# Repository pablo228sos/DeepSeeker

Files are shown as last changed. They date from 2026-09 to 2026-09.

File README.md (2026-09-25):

# DeepSeeker

[English](README.md) | [Русский](README.ru.md)







**A field-evaluated autonomous catamaran for synchronized shallow-water imaging and coverage guidance at Lake Issyk-Kul.**

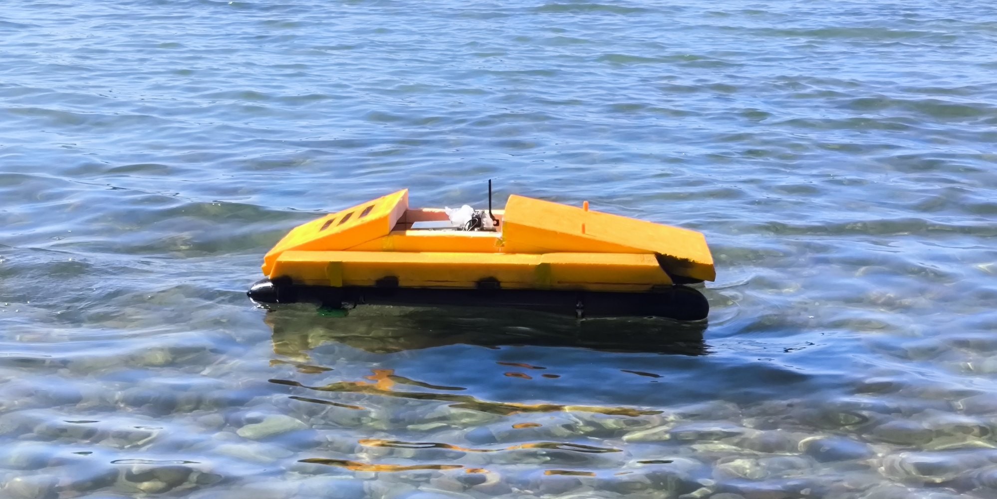
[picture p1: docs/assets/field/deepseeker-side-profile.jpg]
DeepSeeker operating in shallow water at Lake Issyk-Kul


DeepSeeker is a low-cost robotic catamaran built to survey shallow water, capture geotagged underwater imagery, and turn a planned coverage route into a dataset that can be inspected and reconstructed later. The system was designed, assembled, programmed, and tested during the Young Scientists Camp 2026 at Lake Issyk-Kul, Kyrgyzstan.

This repository preserves the recovered engineering record: field firmware, camera firmware, mission-planning tools, raw mission archives, telemetry, reconstruction attempts, successful results, hardware models, and the final research paper. Failed trials are kept beside the successful run because they explain which changes mattered.

<p align="center">
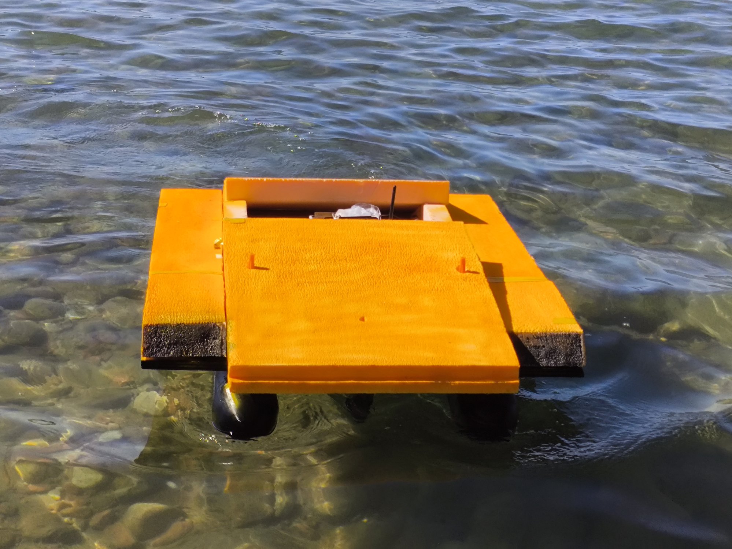
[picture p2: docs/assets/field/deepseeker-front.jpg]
Front view of DeepSeeker in shallow water
  
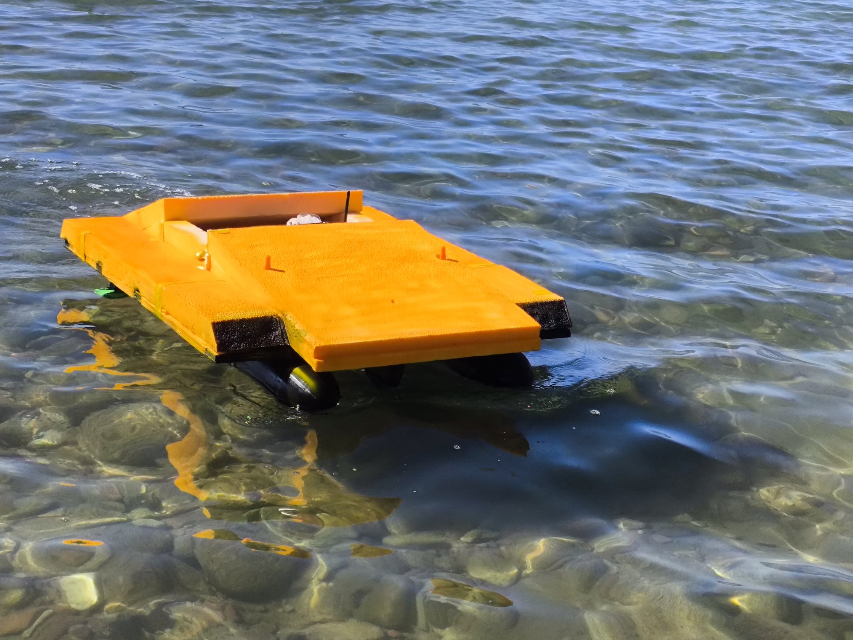
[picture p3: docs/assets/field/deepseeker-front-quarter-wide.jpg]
Front-quarter field view of DeepSeeker
  
</p>

## Mission

We set out to build a small surface vehicle that could define a survey area, follow a coverage pattern, photograph the bottom, and leave behind enough synchronized evidence to reconstruct and audit the mission later. The harder goal was not merely making the boat move. It was connecting navigation, imaging, storage, and honest validation into one field system.

## Field result at a glance

| M0016 measure | Result |
| --- | ---: |
| Images saved | 208 / 208 |
| Mission duration | 279 s |
| Median speed | 0.262 m/s |
| Median capture time | 445.5 ms |
| Median satellites | 6 |
| Median HDOP | 1.56 |
| Connected reconstruction | One outbound-and-return bottom transect |

## System

- A twin-thruster surface catamaran controlled by an ESP32.
- An ESP32-S3 camera node with microSD storage and a downward-looking OV3660 camera.
- GPS, MPU-6050 inertial sensing, differential thrust, manual Wi-Fi control, and autonomous coverage logic.
- Synchronized JPEG, GNSS, IMU, stability, and capture-time logging.
- Four-corner survey definition and lawnmower-style coverage experiments.
- An OpenDroneMap-compatible `geo.txt` export for georeferenced processing.
- A custom feature-aligned corridor reconstruction for the strongest field mission.

## Strongest field result

Mission **M0016** recorded 208 geotagged underwater images during a manually controlled outbound-and-return transect. Every expected frame was saved. The mission lasted 279 seconds, with a median speed of 0.262 m/s and a median image capture time of 446 ms. The GPS solution usually used 5-6 satellites; median HDOP was 1.56.

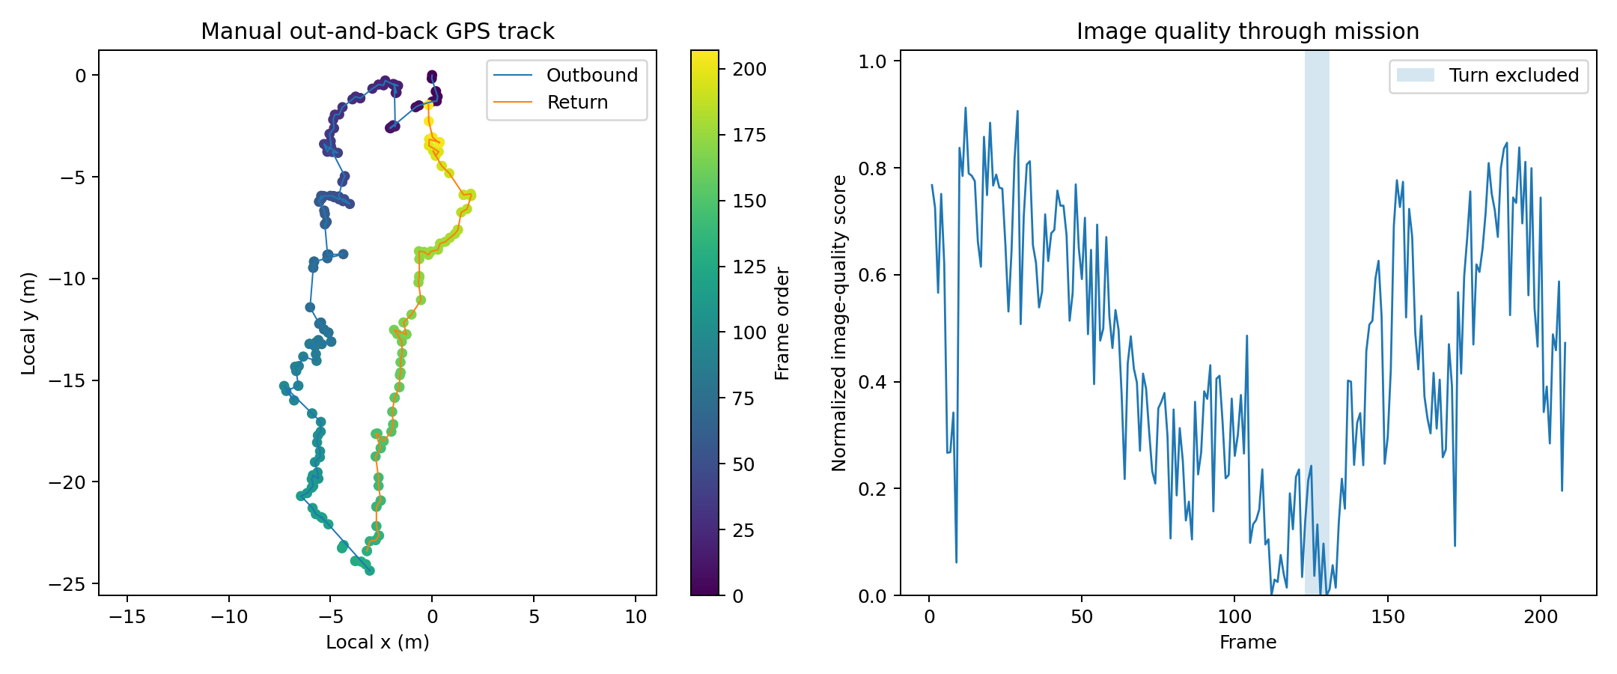
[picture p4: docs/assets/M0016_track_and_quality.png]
M0016 route and image quality


The final processing produced a connected view of the surveyed bottom corridor. It is useful as a visual transect and demonstrates that low-cost synchronized imaging can preserve interpretable bottom texture under field conditions.

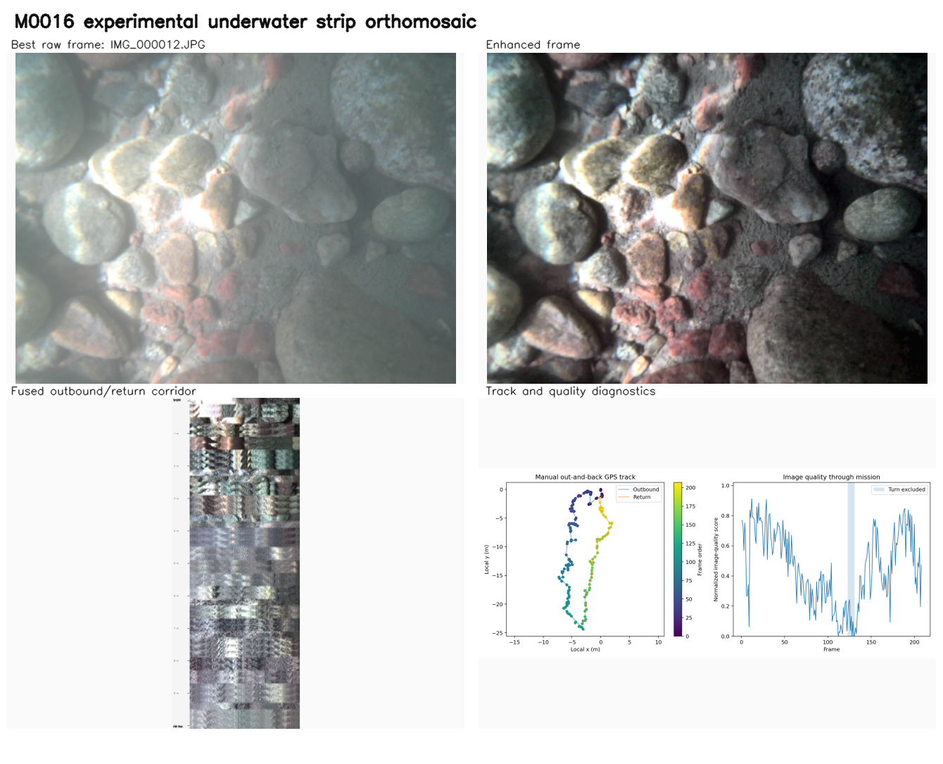
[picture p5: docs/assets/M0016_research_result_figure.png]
M0016 experimental strip mosaic


We deliberately call this an **experimental strip mosaic**, not a survey-grade orthophoto. The run covered one out-and-back corridor rather than a complete grid, the underwater camera was not metrically calibrated, camera height was not measured, and consumer GNSS does not provide survey-grade placement.

## Repository map

| Path | Contents |
| --- | --- |
| [`firmware/`](firmware/) | Main ESP32 controller, ESP32-S3 camera node, field mode, and version history |
| [`data/`](data/) | Raw M0014 and M0016 archives, telemetry, `geo.txt`, metrics, and derived results |
| [`analysis/`](analysis/) | Reproducible mission summaries and diagnostic plots |
| [`docs/`](docs/) | Architecture, hardware, field procedure, navigation, imaging, results, and limitations |
| [`hardware/`](hardware/) | Sonar-mount CAD files and hardware notes |
| [`tools/`](tools/) | AquaRoute mission planner and DRSKHUB ground-station prototype |
| [`research/`](research/) | Final 21-page project paper |

## Archive completeness

| Artifact | Status |
| --- | --- |
| Final main-controller firmware | Recovered, checksummed, and compiled |
| Final ESP32-S3 camera firmware | Recovered, checksummed, and compiled |
| M0014 raw mission | Recovered: 362 JPEG images, telemetry, and `geo.txt` |
| M0016 raw mission | Recovered: 208 JPEG images, telemetry, and `geo.txt` |
| Derived diagnostics and mosaics | Recovered and preserved with method notes |
| Original physical microSD card | Lost after the camp |
| Original one-off feature-alignment script | Not recovered; outputs and telemetry-level reproduction are preserved |

The distinction matters: this repository contains every recovered primary artifact, but it does not pretend that missing source material was recovered. See [`docs/reproducibility.md`](docs/reproducibility.md).

## Quick start

Git LFS is required for the two raw mission archives. Python 3.10 or newer is sufficient for the numerical summary.

```bash
git lfs install
git clone https://github.com/pablo228sos/DeepSeeker.git
cd DeepSeeker
python -m pip install -r analysis/requirements.txt

python analysis/deepseeker_analysis.py summarize data/M0016/source/telemetry.csv
python analysis/deepseeker_analysis.py plot \
  data/M0016/source/telemetry.csv \
  --quality-csv data/M0016/derived/M0016_quality_metrics.csv \
  --turn-start 123 \
  --turn-end 131 \
  --output M0016_reproduced.png
```

The raw images are preserved in `data/M0014/raw/M0014.rar` and `data/M0016/raw/M0016.rar`. Their SHA-256 checksums are recorded in [`data/manifest.csv`](data/manifest.csv).

## Imaging workflow

The camera firmware writes each image and its synchronized metadata to microSD. `geo.txt` follows the OpenDroneMap geolocation-file format with `EPSG:4326`, image name, longitude, latitude, and altitude. It can be placed in the image project root for ODM or WebODM processing.

[OpenDroneMap](https://github.com/OpenDroneMap/ODM) was the intended general photogrammetry pipeline. The successful M0016 figure in this repository was produced with a separate feature-aligned corridor workflow because the mission was a single transect and underwater imagery violated several assumptions of ordinary aerial orthophoto reconstruction. See [`docs/imaging-and-mosaics.md`](docs/imaging-and-mosaics.md).

## Read this before reusing the results

DeepSeeker was tested in a real lake with waves, turbidity, moving sunlight, GNSS drift, optical-window effects, and limited field time. These are research data, not certified hydrographic measurements. The project demonstrates a working embedded acquisition platform and a useful visual reconstruction, while documenting the limits that still prevent metric underwater mapping.

Start with:

- [`docs/results.md`](docs/results.md) for the measured outcomes.
- [`docs/limitations.md`](docs/limitations.md) for what the data cannot prove.
- [`docs/field-operations.md`](docs/field-operations.md) before running the vehicle.
- [`docs/bill-of-materials.md`](docs/bill-of-materials.md) for the recovered hardware configuration.
- [`docs/gallery.md`](docs/gallery.md) for field photographs.
- [`docs/roadmap.md`](docs/roadmap.md) for the next validation steps.
- [`research/DeepSeeker_Final_Submission_Mobile_Safe.pdf`](research/DeepSeeker_Final_Submission_Mobile_Safe.pdf) for the complete paper.

## Team

DeepSeeker was developed by **Abai Bakasov, Aikanysh Muratbekova, Najmidin Takhirov, Sharifjon Farmonov, Dinislam Muratov, and Zhuoyin Li** during the Young Scientists Camp 2026.

## License and citation

Source code is released under Apache-2.0. Original documentation, figures, media, and datasets are released under CC BY 4.0 unless a file states otherwise. See [`LICENSE`](LICENSE), [`LICENSE.md`](LICENSE.md), and [`CITATION.cff`](CITATION.cff).

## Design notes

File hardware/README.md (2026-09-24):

# Hardware artifacts

`cad/sonar_mount_v1.stl` and `cad/sonar_mount_v2.stl` preserve two mechanical iterations for the experimental sonar assembly.

The final research claim is based on synchronized camera, GNSS, and IMU acquisition. Sonar depth and material-classification experiments were inconclusive and are documented as development history rather than validated sensing results.

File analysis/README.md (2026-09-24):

# Analysis

`deepseeker_analysis.py` recalculates mission-level metrics directly from camera telemetry and creates a route and quality diagnostic.

## Setup

```bash
python -m pip install -r analysis/requirements.txt
```

The `summarize` command uses only the Python standard library. Matplotlib is required only by `plot`.

## M0016

```bash
python analysis/deepseeker_analysis.py summarize \
  data/M0016/source/telemetry.csv \
  --output analysis/output/M0016_summary.json

python analysis/deepseeker_analysis.py plot \
  data/M0016/source/telemetry.csv \
  --quality-csv data/M0016/derived/M0016_quality_metrics.csv \
  --turn-start 123 \
  --turn-end 131 \
  --output analysis/output/M0016_track_and_quality.png
```

`raw_gps_polyline_m` is the sum of distances between consecutive raw GNSS fixes. It includes GNSS jitter and must not be presented as a calibrated traveled distance.

## Tests

```bash
python -m unittest discover -s analysis/tests -v
```

The historical M0014 and M0016 derived packages are preserved exactly as recovered. The script here provides a clean, reviewable baseline for repeating their telemetry-level analysis.

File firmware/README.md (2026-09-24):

# Firmware

## Final field snapshots

### Main controller

`main-controller/main_esp32_autonomy_v6_0_interlaced_teardrop/`

Target: classic ESP32 development board.

External Arduino libraries:

- TinyGPSPlus
- ESP32Servo

The ESP32 Arduino core supplies Wi-Fi, WebServer, Preferences, Wire, and HardwareSerial.

### Camera controller

`camera-controller/esp32_s3_camera_mission_v2_2_sd_retry/`

Target: GOOUUU ESP32-S3-CAM V1.5 with OV3660 and PSRAM.

The sketch uses the camera, FS, SD_MMC, Wi-Fi, and WebServer components supplied by the ESP32 Arduino core. Board pin definitions are specific to the tested camera module.

### Manual 10 x 10 m field mode

`field-mode/main_esp32_10x10_manual_orthophoto_v1_0/`

This variant was prepared for deliberate parallel-lane image collection when a full autonomous area mission was too risky for the available test window.

## Upload order

1. Remove or mechanically isolate propellers.
2. Upload the camera sketch to the ESP32-S3-CAM.
3. Confirm camera initialization, PSRAM, SD mounting, and a saved test image.
4. Upload the main-controller sketch to the ESP32.
5. Verify UART communication and camera-ready status.
6. Confirm ESC neutral before allowing any motor command.

## Historical credentials

The preserved field snapshots use the test password `12345678`. This is part of the historical record, not a secure deployment default. Change it before reuse.

## Version archive

`archive/` contains the sequence of field iterations. These are evidence of development and may contain incomplete or experimental behavior. Use the final snapshots above unless reproducing a specific trial.

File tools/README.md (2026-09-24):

# Planning and ground-station tools

## AquaRoute Mission Planner

The browser-based AquaRoute prototype allows a route to be drawn and exported as JSON. It is preserved as a planning experiment. It was not directly integrated with the final ESP32 upload path.

Open `AquaRoute_Mission_Planner/index.html` in a browser to inspect it.

## DRSKHUB

DRSKHUB is a PyQt6/MAVLink ground-station prototype with map, mission, telemetry, parameter, simulation, and fleet panels. It predates the final lightweight ESP32 workflow and is included as a separate software experiment. The local virtual environment has been excluded.

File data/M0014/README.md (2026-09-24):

# Mission M0014

M0014 was a long camera and telemetry run with 362 saved images. It proved that the acquisition pipeline could operate continuously, but only about 8% of frames passed a moderate local-detail threshold. Even the clearest continuous section could not support a valid metric orthophoto.

The main lesson was optical: speed and onboard stability did not explain the softness. Focus through the housing, water clarity, camera distance, window condition, and illumination needed attention before route refinements could matter.

See [`derived/M0014_analysis_report.md`](derived/M0014_analysis_report.md) for the complete diagnostic.

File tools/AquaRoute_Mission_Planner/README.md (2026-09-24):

# AquaRoute Mission Planner v1.0

Первая браузерная версия редактора маршрутов для автономного катамарана на ESP32.

## Запуск

1. Распакуйте архив.
2. Откройте `index.html` в браузере.
3. Для загрузки карты нужен интернет.
4. Кликайте по карте для добавления контрольных точек.
5. Перетаскивайте маркеры для исправления маршрута.
6. Правый клик по маркеру удаляет его.
7. Нажмите `Скачать mission.json`.

## Что находится в mission.json

- название миссии;
- скорость;
- радиус достижения точки;
- HOME;
- исходные контрольные точки;
- автоматически созданные промежуточные точки для ESP32.

## Важное ограничение

Это планировщик маршрута. Он еще не отправляет файл прямо на ESP32. Следующий модуль — веб-панель ESP32 для загрузки `mission.json`, сохранения в LittleFS и запуска миссии.

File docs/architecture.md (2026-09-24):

# System architecture

DeepSeeker separates motion control from image acquisition. The main ESP32 keeps the vehicle controllable even if the camera is busy writing a large JPEG, while the ESP32-S3-CAM owns the camera and microSD card.

```mermaid
flowchart LR
    Phone[Phone / field operator] <-->|Wi-Fi AP| Main[Main ESP32]
    GPS[NEO-6M GNSS] -->|UART2| Main
    IMU[MPU-6050] -->|I2C| Main
    Main -->|PWM| Left[Left ESC and thruster]
    Main -->|PWM| Right[Right ESC and thruster]
    Main <-->|UART1 commands and status| Cam[ESP32-S3-CAM]
    Cam --> Sensor[OV3660]
    Cam --> SD[microSD]
```

## Main controller responsibilities

- Arm and command both ESCs.
- Read GNSS and IMU data.
- Serve the local control page over Wi-Fi.
- Store survey corners and generate coverage paths.
- Follow waypoints with differential thrust.
- Request camera captures and monitor acknowledgements.
- Apply timeouts, GNSS-quality gates, and stop behavior.

## Camera controller responsibilities

- Initialize the OV3660 and PSRAM.
- Mount microSD in one-bit SD_MMC mode.
- Create numbered mission directories.
- Capture full-resolution JPEG images.
- Append synchronized metadata to `telemetry.csv` and `geo.txt`.
- Retry microSD initialization after temporary failures.
- Report readiness and capture status to the main controller.

## Why two controllers

JPEG capture and SD writes can take hundreds of milliseconds. In M0016 the median capture time was 445.5 ms. Keeping that workload on a second controller prevents image storage from blocking the motor, GNSS, and safety loops on the main ESP32.

The Wi-Fi interfaces are for setup, diagnostics, and manual control. Autonomous navigation runs locally and does not depend on a continuous phone connection.

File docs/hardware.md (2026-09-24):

# Hardware and wiring

## Field configuration

| Component | Main ESP32 connection | Notes |
| --- | --- | --- |
| Left ESC signal | GPIO25 | Tested physical left thruster |
| Right ESC signal | GPIO2 | Tested physical right thruster; boot-strap pin, keep the ESC signal electrically quiet during reset |
| GPS TX | GPIO16 / UART2 RX | Required for GNSS input |
| GPS RX | GPIO17 / UART2 TX | Optional unless configuring the receiver |
| MPU-6050 SDA | GPIO21 | I2C |
| MPU-6050 SCL | GPIO22 | I2C |
| Camera UART TX | GPIO14 to S3 GPIO1 | Main controller to camera |
| Camera UART RX | GPIO13 from S3 GPIO2 | Camera to main controller |
| Common ground | GND | Required across both ESP32 boards, GPS, IMU, and ESC signal grounds |

## Camera board

The final camera firmware targets a GOOUUU ESP32-S3-CAM V1.5 with an OV3660. Camera and SD pins are board-specific and are defined near the top of the camera sketch. The SD card uses SD_MMC one-bit mode on GPIO39, GPIO38, and GPIO40.

## Power

- Do not power both ESP32 boards from multiple 5 V regulators unless their interaction is understood.
- Keep all control grounds common.
- Use a regulator with enough transient current for Wi-Fi, camera, PSRAM, and SD writes.
- Keep motor power wiring away from GPS, camera, and UART wiring.
- Add local decoupling near each controller and verify voltage during simultaneous motor and camera activity.

## ESC behavior measured on the boat

The final main-controller snapshot uses:

| Pulse | Meaning on this vehicle |
| --- | --- |
| 1500 us | Neutral / stop |
| Lower than 1500 us | Forward thrust |
| 1000 us | Maximum tested forward command |

This mapping is specific to the tested ESC setup. Confirm neutral and direction with propellers removed before copying it to another vehicle.

## Mechanical files

Two sonar-mount iterations are preserved in [`../hardware/cad/`](../hardware/cad/). The sonar work remained experimental and was not the basis of the final imaging result.

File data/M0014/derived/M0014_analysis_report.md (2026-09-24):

# M0014 photo and orthomosaic diagnostic

## Dataset

- 362 JPEG images at 2048×1536.
- Median interval between images: approximately 1 second.
- Mean recorded speed: approximately 1.76 km/h (0.49 m/s).
- Median GPS displacement between consecutive images: approximately 0.55 m.
- Median camera capture/save time: approximately 300 ms.

## Result of stitching attempt

A feature- and optical-flow-based stitch was attempted on frames 270–290, the clearest continuous section. The output is included as `M0014_orthomosaic_attempt_diagnostic.png`.

It is not a valid metric orthophoto. The algorithm cannot find enough stable common details between most consecutive frames. The main limitations are severe optical softness/haze and insufficient reliable image texture, not simply route coverage.

## Image-quality findings

- Only about 8% of frames exceed a moderate local-detail threshold.
- The clearest continuous group is approximately frames 270–288.
- Measured sharpness has almost no relationship with recorded speed or the `stable` flag.
- Very slow or nearly stationary frames are also soft.

This indicates that timing alone will not solve the problem. The dominant cause is optical: turbidity, camera focus through the waterproof window, dirty/condensed window, excessive camera-to-bottom distance, or a combination of these.

## Recommended capture logic for the next 10×10 m run

1. Before the mission, stop the robot above visible bottom and capture 5 test images.
2. Do not start the grid unless the test image contains clearly defined stone edges at full resolution.
3. Use 0.20–0.30 m/s on photo strips.
4. Use an 800–900 ms photo interval.
5. Use strips 0.7–0.8 m apart for the first pass.
6. Repeat a second pass perpendicular to the first when time permits.
7. Photograph only while moving approximately straight; pause automatic capture during turns.
8. Continue after one failed capture; stop only after several consecutive failures.
9. Log the distance traveled since the last saved image and request another image after 0.20–0.25 m, with a time fallback of 900 ms.
10. Reject or mark frames captured during high yaw rate or strong roll/pitch, but force a capture if the distance threshold is exceeded.

## Hardware check before changing software again

- Clean both sides of the camera window.
- Check for condensation or a water film.
- Test focus in a bucket or at the real operating depth using stones with sharp edges.
- Adjust the OV3660 lens focus physically if the module permits it.
- Keep the camera as close to the bottom as safely possible.
- Add downward lighting only if it does not illuminate suspended particles directly in front of the lens.

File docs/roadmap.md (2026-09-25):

# Roadmap

The next stage is not adding more interface features. It is closing the measurement gaps exposed by the field data.

## 1. Recover the physical specification

- Measure hull length, beam, mass, camera offset, and antenna offset.
- Record battery, regulator, ESC, and thruster model numbers.
- Draw a complete power and signal schematic.
- Photograph the internal electronics and camera installation.

## 2. Validate autonomous coverage

- Use a tethered-water test before every unrestricted mission.
- Record the four-corner input, generated lanes, commanded PWM, GNSS course, cross-track error, and interventions.
- Define pass criteria for lane completion, turn overshoot, area coverage, and safe return.
- Compare manual and autonomous routes over the same marked area.

## 3. Calibrate the imaging system

- Calibrate the camera underwater through the installed housing window.
- Measure camera-to-bottom distance during capture.
- Add scale targets and independently surveyed control points.
- Repeat parallel lanes with measured forward and lateral overlap.

## 4. Improve positioning and heading

- Evaluate RTK GNSS for the surface platform.
- Add a calibrated magnetometer or dual-antenna heading source.
- Log controller state and heading uncertainty beside every frame.

## 5. Rebuild the reconstruction pipeline

- Reimplement the feature-aligned corridor workflow as versioned source code.
- Add synthetic and field regression datasets.
- Export a complete provenance record for every generated mosaic.
- Validate scale and placement against independent measurements before using the word orthophoto without qualification.

## 6. Revisit sonar separately

Sonar depth and material experiments should remain a separate workstream until a repeatable calibration rig and known targets are available. Camera results must not be used to imply sonar validation, or vice versa.

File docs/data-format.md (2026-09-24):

# Data format

## Mission directory

Each camera mission contains numbered JPEG files plus two text products:

```text
M0016/
  IMG_000001.JPG
  IMG_000002.JPG
  ...
  telemetry.csv
  geo.txt
```

## `telemetry.csv`

| Column | Unit or meaning |
| --- | --- |
| `image` | JPEG filename |
| `utc` | ISO 8601 UTC timestamp |
| `latitude`, `longitude` | WGS84 decimal degrees |
| `altitude_m` | GNSS altitude in metres |
| `satellites` | Satellites used by receiver |
| `hdop` | Horizontal dilution of precision |
| `speed_kmph` | GNSS ground speed |
| `course_deg` | GNSS course over ground |
| `roll_deg`, `pitch_deg` | IMU attitude estimate |
| `gyro_x_dps`, `gyro_y_dps`, `gyro_z_dps` | Angular rate in degrees per second |
| `total_acc_g` | Acceleration magnitude in g |
| `stable`, `level` | Onboard diagnostic flags, 0 or 1 |
| `jpeg_bytes` | Saved JPEG size |
| `capture_ms` | Capture and storage duration |

The `stable` and `level` flags are diagnostic labels based on onboard thresholds. They are not proof that a frame is sharp.

## `geo.txt`

The first line declares the coordinate reference system. Remaining lines contain image name, longitude, latitude, and altitude:

```text
EPSG:4326
IMG_000001.JPG 77.0738157 42.6398862 1621.30
```

The longitude-before-latitude order follows the OpenDroneMap geolocation-file convention.

## Integrity

Raw archives are immutable inputs. Derived metrics and figures must be written outside the archive and described by a method note. [`../data/manifest.csv`](../data/manifest.csv) records checksums and mission-level contents.

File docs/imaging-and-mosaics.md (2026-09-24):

# Imaging and mosaics

## Acquisition record

Every saved JPEG has a matching row in `telemetry.csv`. The row includes UTC time, latitude, longitude, altitude, satellite count, HDOP, speed, GNSS course, roll, pitch, angular rates, total acceleration, stability flags, JPEG size, and capture duration.

`geo.txt` is prepared for OpenDroneMap and WebODM:

```text
EPSG:4326
IMG_000001.JPG longitude latitude altitude
```

## OpenDroneMap

[OpenDroneMap](https://github.com/OpenDroneMap/ODM) was the intended general-purpose reconstruction tool. The mission image directory and `geo.txt` can be imported into ODM or WebODM using its [geolocation file format](https://docs.opendronemap.org/geo/). This is useful for testing feature matching, camera reconstruction, dense point clouds, and orthophoto output.

Underwater imagery is harder than ordinary aerial imagery. Refraction through water and the housing window changes the effective camera model. Turbidity, caustic sunlight, weak texture, and a moving surface vehicle further reduce stable feature matches. GNSS measures the boat antenna rather than each bottom point, and no camera-to-bottom range was logged.

## M0014 diagnostic

M0014 contained 362 images, but most frames were too soft or hazy for reliable sequential registration. A focused attempt on frames 270-290 still failed to produce a valid metric orthophoto. This result showed that increasing overlap alone would not fix the optical problem.

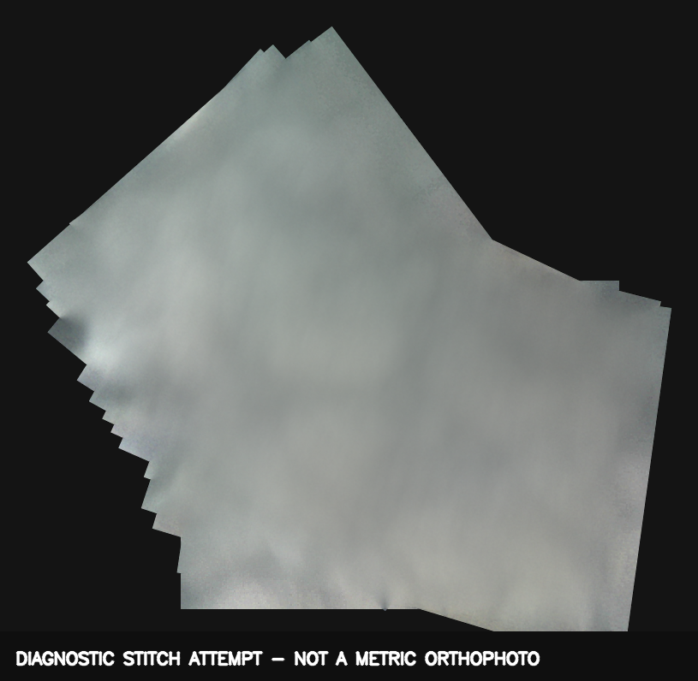
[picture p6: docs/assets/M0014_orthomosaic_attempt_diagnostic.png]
M0014 failed stitching diagnostic


## M0016 corridor reconstruction

M0016 used one outbound-and-return corridor. Turning frames were excluded. Return images were rotated so both passes shared a common ground orientation. Frames were scored by sharpness, contrast, tonal range, and inertial stability. A pushbroom-style strip result and a feature-aligned connected result were produced.

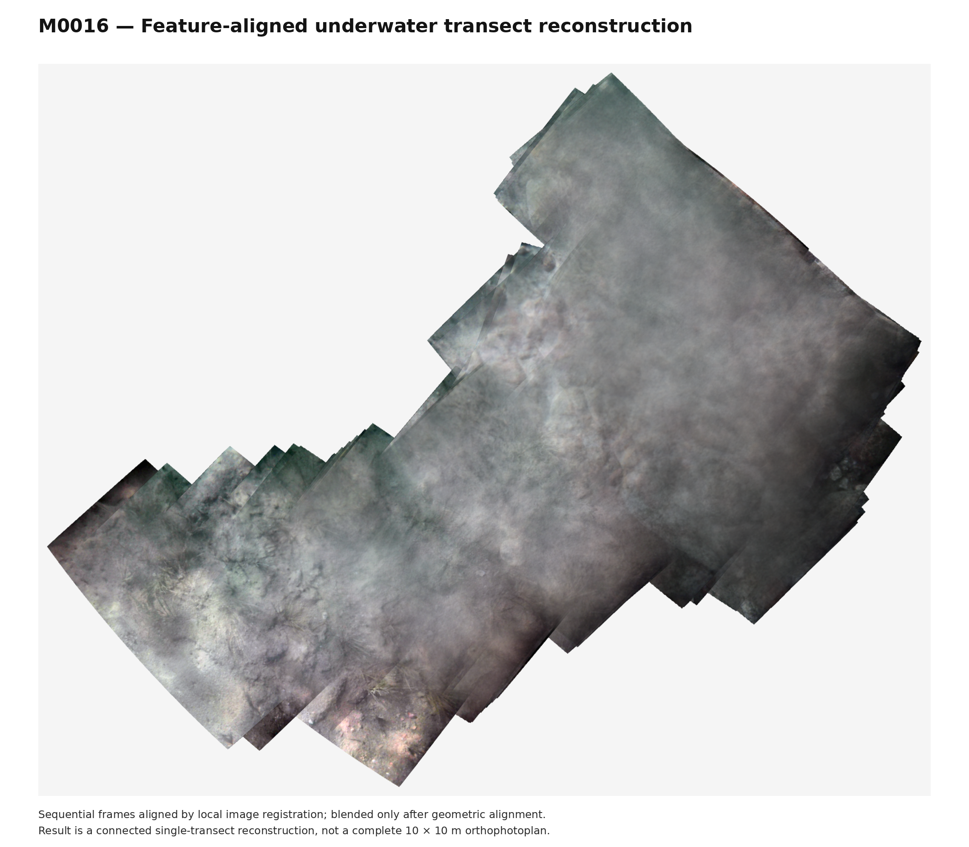
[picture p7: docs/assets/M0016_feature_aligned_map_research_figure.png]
M0016 feature-aligned connected map


This reconstruction is scientifically useful as a connected visual transect. It is not a complete 10 x 10 m orthophoto and it does not provide calibrated scale or survey-grade geolocation.

## Requirements for a metric area product

- Calibrate the camera in water through the actual housing window.
- Measure or estimate camera-to-bottom distance for every frame.
- Capture a full parallel-lane grid with measured lateral overlap.
- Add scale bars, targets, or surveyed control points.
- Improve positioning with RTK GNSS or a locally surveyed reference.
- Record and compensate camera lever arm and orientation.
- Validate dimensions against independent measurements.

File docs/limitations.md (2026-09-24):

# Limitations

DeepSeeker is a field-tested research prototype. The following limits are part of the result, not footnotes to hide.

## Positioning

The NEO-6M-class receiver provides consumer GNSS positioning. Five or six satellites and an HDOP near 1.5 can support route guidance, but they do not guarantee centimeter accuracy. Repeated coordinates, lag, multipath, and short-term drift are visible in the logs.

## Heading

The MPU-6050 measures angular rate and acceleration but has no magnetometer. Absolute heading is inferred mainly from GNSS course while moving. Heading is therefore weak at low speed and during the first part of a turn.

## Imaging geometry

The camera was not calibrated underwater through the installed window. Camera height above the bottom was not logged, the lakebed was not planar, and the housing introduces refraction. The resulting mosaic cannot be treated as a metrically rectified map.

## Water and light

Turbidity, suspended particles, glare, caustic sunlight, waves, and low-texture sand change from frame to frame. These effects can defeat feature matching even when route overlap is high.

## Mission coverage

M0016 was one outbound-and-return corridor, not a complete area grid. The connected result demonstrates transect reconstruction only.

## Sonar

The sonar and analog-amplifier tests are part of the project history, but their lake readings were inconsistent and were not used to support the final mapping claim. Material discrimination was not validated.

## Safety

The vehicle has no certified obstacle avoidance, redundant navigation computer, geofence guarantee, or independent emergency-stop radio. All tests require direct supervision and a recovery plan.

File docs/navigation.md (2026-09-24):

# Navigation and coverage

## Mission definition

The field workflow records four GNSS corner positions. Each point is averaged for six seconds instead of accepting a single noisy fix. The controller checks the resulting quadrilateral before generating a route.

The planned path uses parallel survey lanes joined by rounded turns. The later firmware history includes lawnmower coverage, four-corner matching, connector-stop fixes, and an interlaced teardrop path. Those versions are preserved in `firmware/archive/` so that route behavior can be traced to a specific test.

## Heading estimation

GNSS alone gives position and, while moving, course over ground. It does not directly tell the controller where the bow points when the boat is stationary or moving slowly. The MPU-6050 supplies yaw-rate damping and attitude diagnostics, but without a magnetometer it does not provide an absolute north reference.

The controller therefore relies on GNSS course during forward motion, local path geometry, differential thrust, and IMU damping. This works best with continuous, gentle turns and enough forward speed for the GNSS course to become meaningful.

## GNSS gates in the final firmware

- At least 5 satellites for autonomous operation.
- HDOP no greater than 3.5.
- Position and course freshness checks.
- A local stop if manual commands expire.

These are operational thresholds, not guarantees of metric accuracy. M0016 commonly used 5-6 satellites and had median HDOP 1.56.

## Why earlier autonomous runs circled

Several effects can produce circles or a figure-eight path:

- Course over ground becomes unstable near zero speed.
- A turn command can remain active while the GPS course lags behind the real bow motion.
- Unequal thrusters create a persistent steering bias.
- Closely spaced waypoints can fall inside GNSS noise.
- A return target can be approached with the wrong assumed heading.

The later firmware addresses these issues with motor trim, quality gates, approach logic, rounded connectors, speed scheduling, and yaw-rate damping. Full autonomous area coverage was not validated to the same level as the synchronized imaging pipeline, so it remains an experimental subsystem.

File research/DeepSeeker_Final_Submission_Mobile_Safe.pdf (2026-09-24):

DeepSeeker | Field-evaluated shallow-water robotic imaging platform

## DeepSeeker: A Field-Evaluated Embedded Catamaran for

## Synchronized Shallow-Water Imaging and Coverage Guidance at Lake Issyk-Kul

Abai Bakasov | Aikanysh Muratbekova | Najmidin Takhirov
Sharifjon Farmonov | Dinislam Muratoz | Zhuoyin Li

Young Scientists Camp 2026, Lake Issyk-Kul, Kyrgyz Republic Original Research Article · Field dataset M0016 · 18 July 2026

Abstract

Shallow littoral zones are difficult to inspect repeatedly with conventional survey vessels, yet they are the part of a lake most exposed to recreation, shoreline activity, and visible submerged debris. This paper presents DeepSeeker, a locally developed differential-thrust catamaran designed to collect spatially organized underwater imagery in the nearshore zone of Lake Issyk-Kul. The platform separates navigation and imaging between a Main ESP32 and an ESP32-S3-CAM equipped with an OV3660 sensor. GNSS, inertial, motor, and capture metadata are transmitted over UART; each QXGA JPEG is written to microSD together with a telemetry row and a geographic record. The complete raw archive from mission M0016 contains 208 images, 208 telemetry records, and 208 geotag entries acquired over 279 s. Median vessel speed was 0.262 m s⁻¹
, median capture latency was 446 ms, and GNSS quality ranged from five to six satellites with HDOP 1.55–2.35. The mission formed an approximately 24.6 m out-and-back corridor and produced one connected feature-aligned underwater transect mosaic. It also exposed the decisive limitation of the prototype: a single low-cost GNSS receiver and a six-axis IMU do not provide absolute bow heading during low-speed manoeuvres. To address the geometric part of the problem, the firmware implements manual initial heading, gyroscope propagation, guarded course-over-ground correction, interlaced strip ordering, and forward-only bounded-curvature transitions. A complete multi-strip coverage mission, however, was not field-validated. The contribution is therefore not an overstated claim of precision hydrography, but a reproducible embedded architecture, a complete field dataset, a quantitative failure analysis of heading observability, and a controlled experimental roadmap toward accurate mapping, local debris detection, and acoustic sensing.

Keywords: autonomous surface vehicle; shallow-water imaging; image mosaicking; coverage planning; embedded sensing; Lake Issyk-Kul

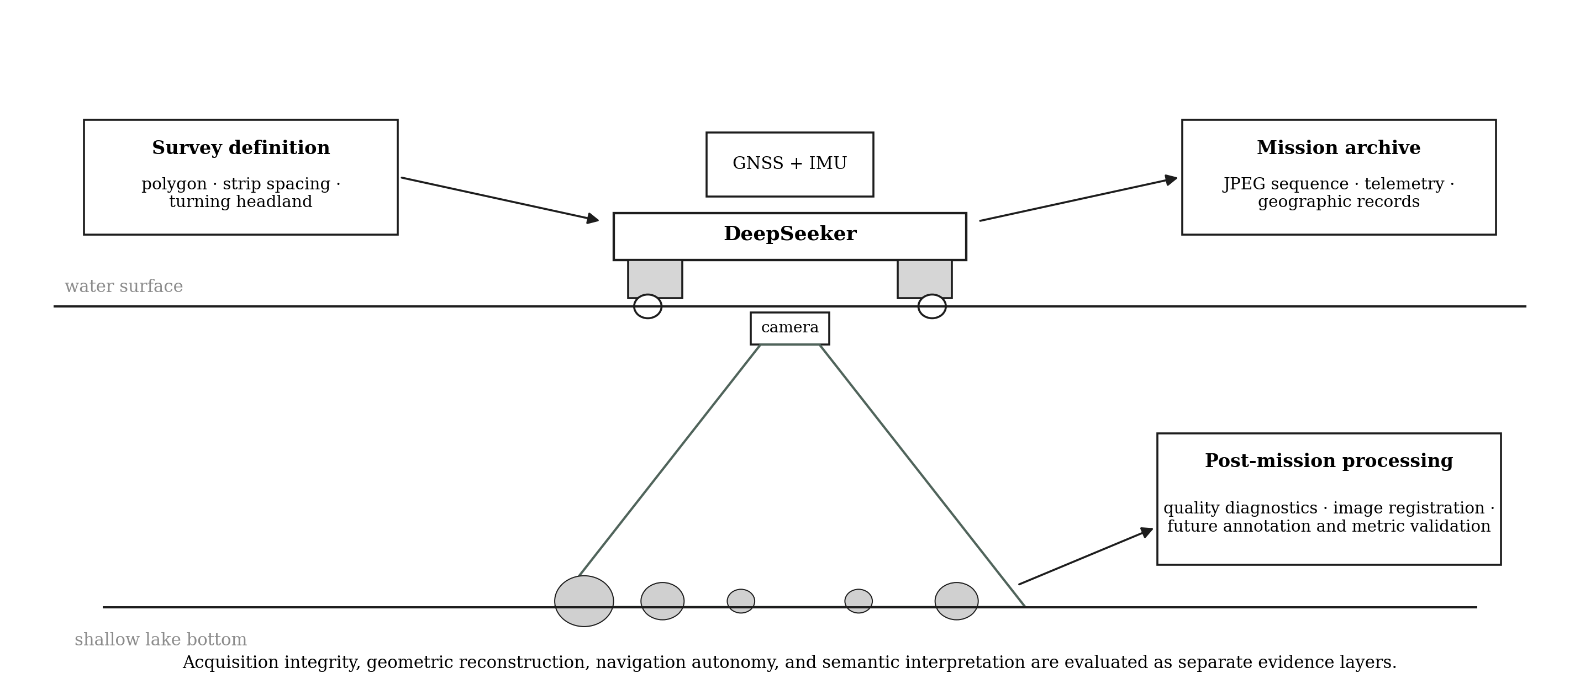
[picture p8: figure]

Figure 1: DeepSeeker mission concept. The platform couples survey definition, surface navigation, downward-looking image acquisition, synchronized mission logging, and post-mission analysis. The manuscript treats acquisition integrity, geometric reconstruction, navigation autonomy, and semantic interpretation as separate evidence layers.

### 1 Introduction

Lake margins occupy an uncomfortable space between terrestrial and marine surveying. They are often too shallow, confined, or obstacle-rich for conventional survey boats, yet they are difficult to inspect systematically by wading or diving. Manual inspection is slow, exposes people to cold water and unstable ground, and rarely reproduces exactly the same path on a later date. These limitations matter at Lake Issyk-Kul, where recreational use, coastal development, natural sediment transport, and environmental protection coexist in a narrow nearshore zone. The lake and its surrounding landscape form a UNESCO biosphere reserve, while sediment-core studies show a long-term record of anthropogenic inputs [1, 2]. A small robotic platform cannot replace chemical analysis, ecological sampling, or certified hydrographic survey. It can, however, create repeatable visual evidence, document the spatial distribution of visible objects, and provide a locally maintainable experimental base for more advanced sensors.
Autonomous and semi-autonomous surface vehicles have become practical carriers for cameras, water-quality probes, echo sounders, and acoustic receivers. Catamaran geometry is common because two separated hulls provide a broad support polygon, a central payload area, and direct differential steering. The same geometry appears in systems of very different maturity. CORAL is a 1.84 m research catamaran carrying inertial navigation, GNSS, cameras, a single-beam echo sounder, and side-scan sonar [6]. Reef Rover used a small autonomous surface vehicle and consumer cameras to acquire shallow coral-reef imagery, but its authors documented that insufficient overlap in one configuration prevented direct reconstruction until manual intervention was introduced [7]. Gogendeau et al. developed an open and reproducible multimodal ASV for acoustic tracking, bathymetry, and photogrammetry, with separate field case studies for each function and a sensor-dependent cost of several thousand dollars [8]. These systems show that a convincing research vehicle is not defined by a photograph of the platform or by the nominal presence of sensors. Its scientific value depends on synchronized acquisition, explicit coordinate frames, field validation, and error analysis.
The present project began under a different constraint. DeepSeeker was designed, constructed, wired, programmed, and tested during a short field camp using locally available components. The prototype therefore used a Main ESP32, an ESP32-S3-CAM with an OV3660 sensor, a GY-NEO6MV2 receiver, an MPU-6050, two electronic speed controllers, and two submerged thrusters. The design objective was not merely remote control. The intended mission was a lawnmower-style survey in which the catamaran would traverse parallel strips, capture overlapping underwater images, and produce a coherent visual map of the lake bottom. That objective immediately coupled three problems that are often discussed separately: vehicle guidance, underwater imaging geometry, and data integrity.

Coverage guidance is more demanding than waypoint navigation. A vessel can reach isolated coordinates while still producing an unusable image sequence. Photographic coverage requires repeatable strip spacing, along-track overlap, controlled speed, and entry into each line with a suitable orientation. The vehicle must also leave enough external space for turns, because a compact 180◦ pivot can destroy the very navigation information needed to complete the manoeuvre. Coverage-path planning has a long history in robotics [3, 4]. Recent work for environmental-monitoring USVs combines parallel sweep lines with Dubins connectors and validates the route in real water rather than simulation alone [5]. This is directly relevant to DeepSeeker: a wide forward-only transition may be less geometrically compact than a pivot, but it better matches the hydrodynamics of a small twin-thruster craft and preserves translational motion.
The central navigation difficulty was not a lack of code. It was a lack of absolute heading observability. The MPU-6050 measures angular rate, so yaw can be propagated only by integration and therefore drifts with bias. A single-antenna GNSS receiver reports position and course over ground, but course over ground is the direction of translation, not the orientation of the bow. It becomes unreliable or stale when speed is low, especially during a tight turn. Wind and surface current can also separate the direction of travel from the direction in which the hull points. Consequently, an algorithm may know approximately where the boat is while still not knowing which way its bow is facing. This distinction explains why increasingly complex software cannot fully compensate for an unobservable state.
Underwater imagery adds a second class of uncertainty. The number of stable visual correspondences changes with bottom texture, suspended material, sunlight caustics, camera motion, and distance to the bottom. A camera mounted behind a flat underwater window also violates the ideal pinhole model because rays refract through water, the window material, and air. Ignoring this geometry introduces systematic reconstruction error [9]. Accurate metric products require calibration in the final housing, a rigid and known camera-to-port geometry, independent scale, and check points [10, 11]. Without these elements, a connected mosaic can be a useful visual product but should not be called a metrically validated orthophoto.
Semantic detection is downstream of both navigation and imaging. Public datasets such as SeaClear and TrashCan demonstrate that submerged debris can be detected and segmented with modern neural networks [12, 13]. They also show that performance changes sharply between sites, cameras, and water conditions. A model trained on neighbouring frames from the same mission may appear accurate while failing on a new beach or on a day with different visibility. Therefore, a local YOLO pipeline requires mission-separated train, validation, and test sets. It also requires a clear distinction between a frame-level acquisition coordinate and the true coordinate of an object on the bottom.
This work is structured around evidence rather than intended capability. It asks three questions. First, can a two-controller embedded system preserve a complete sequence of high-resolution underwater images with synchronized navigation records during a real field mission? Second, what does the M0016 archive reveal about the suitability of a single GNSS receiver and a gyroscope-only yaw estimate for compact area coverage? Third, which controlled experiments are required before the imaging, acoustic, and object-detection branches support quantitative environmental claims?
The paper makes five contributions. It documents the complete embedded architecture and capture transaction; analyses all 208 frames and telemetry records from M0016; identifies low-speed heading observability as the dominant limit to lawnmower coverage; formalizes the implemented forward-only transition strategy; and converts unfinished extensions into preregistered experiments rather than retrospective claims. The result is a field-evaluated systems paper and a development baseline for a substantially stronger second-generation platform.

### 2 Research Context and Competitive Positioning

A competitive paper does not become strong by imitating the hardware of a mature platform. It becomes strong by matching the discipline with which mature work defines requirements, validates subsystems, and separates measured performance from design intention. The reference systems considered here illustrate four different standards of evidence.
Reef Rover is particularly relevant because its scientific value includes a documented failure. The vehicle collected imagery suitable for coral mapping, but one configuration did not maintain sufficient overlap for automatic reconstruction [7]. The authors did not hide the failure; they used it to identify speed, depth, and camera arrangement as design variables. This is a useful precedent for DeepSeeker. The absence of a successful full lawnmower mission is not a reason to invent one. It is an opportunity to show why the original navigation stack failed and how the next experiment should isolate the cause.
CORAL demonstrates the importance of multisensor integration. Its navigation, scientific payloads, and operating modes are described as parts of one system rather than as independent modules [6]. The platform is larger and more capable than DeepSeeker, but its design principle is transferable: navigation timestamps, payload timestamps, and sensor geometry must be treated consistently. DeepSeeker approaches this requirement through a simpler dual-controller architecture in which each image receives an associated telemetry record and geotag. The ASV of Gogendeau et al. is the most direct benchmark for research structure. The paper first defines operational requirements, then explains mechanical, electrical, and software design, and finally validates separate mission types with dedicated field surveys [8]. Its strength is not decorative design. It is the chain from requirements to hardware to field results. The current DeepSeeker dataset is narrower, but it supports the same kind of disciplined structure: requirements, implementation, complete raw archive, quantitative results, failure analysis, and next-stage validation.
Commercial BlueBoat-class platforms define a different benchmark. They provide modern GNSS, absolute heading from multiple compasses, mature autopilot software, standardized failsafes, and documented integration with sonar and communications. A first prototype built during a camp should not claim parity with such a system. Its credible competitive advantage lies elsewhere: local maintainability, inspectable code, repairable construction, and an architecture that can be upgraded incrementally. Cost remains relevant, but cost without positioning accuracy, heading observability, endurance, or validated payload performance is not a research contribution. Table 1 therefore compares evidence rather than marketing claims. DeepSeeker already has a complete field archive and an implemented coverage planner. It does not yet have an absolute heading source, independent trajectory ground truth, calibrated photogrammetry, or validated semantic detection. The competitive research opportunity is to make those boundaries explicit and to define experiments that convert each limitation into a measurable engineering question.

Table 1: Positioning of DeepSeeker relative to representative research and commercial platforms.

Platform | Navigation and control | Primary payloads | Evidence available in the cited
| | | work
DeepSeeker | Single GNSS, six-axis IMU,
| manual initial yaw, differential
| thrust, implemented bounded-
| curvature coverage planner | OV3660 underwater camera;
| | exploratory analog acoustic
| | branch | 208-image field transect with
| | | complete metadata; full grid,
| | | metric mapping, acoustic clas-
| | | sification, and YOLO evalua-
| | | tion not yet validated
Reef Rover [7] | Autonomous transects on a
| small USV | Consumer cameras for coral
| | mapping | Field imagery and SfM prod-
| | | ucts; insufficient-overlap fail-
| | | ure documented and discussed
CORAL [6] | GNSS/INS-supported | au-
| tonomous, semi-autonomous,
| and assisted operation | Cameras, echo sounder, side-
| | scan sonar | Multiple coastal field surveys
| | | and integrated sensor architec-
| | | ture
Gogendeau et al. [8] | Research-grade autonomous
| navigation with RTK-capable
| positioning | Acoustic tracking, bathymetry,
| | photogrammetry | Dedicated field case study for
| | | each mission; coverage, en-
| | | durance, and accuracy quan-
| | | tified
BlueBoat-class commercial platform | Modern GNSS, dual com-
| passes, mature autopilot and
| failsafes | Modular camera, communica-
| | tion, and sonar integrations | Commercially documented en-
durance, | waypoint modes,
| | | telemetry, and integration path-
| | | ways

### 3 System Requirements and Design Rationale

The prototype was evaluated against requirements that are achievable for a first field system and relevant to later scientific use. These requirements were divided into platform, acquisition, guidance, safety, and evidence categories. The separation is important because a vehicle can satisfy one category while failing another. For example, the boat may remain stable and preserve every image while still being unable to enter the next survey strip with the required heading.
The platform had to be deployable from shore, carry the control electronics above the waterline, hold a camera below the surface, and maintain low-speed stability. The acquisition system had to save original high-resolution images locally, associate each image with navigation metadata, and continue after short storage or communication failures. Guidance had to support manual operation, straight segments, and an upgrade path toward multi-strip coverage. Safety required common-ground wiring, controlled arming, loss-of-GNSS handling, excessive-tilt detection, camera supervision, geofence logic, and a no-progress timeout. Finally, the evidence requirement demanded that design intent, firmware implementation, and field demonstration remain separate in the manuscript.

Table 2: DeepSeeker design requirements and present evidence status.

Requirement class | Requirement | Current evidence
Deployment | Shore-deployable catamaran with stable low-speed operation and pro-
| tected electronics | Demonstrated in
| | repeated field
| | operation and M0016
| | photographs
Acquisition | High-resolution underwater frames stored independently of radio cover-
| age | Demonstrated: 208
| | QXGA JPEGs stored
| | locally
Synchronization | One navigation record and one geographic record for every requested
| image | Demonstrated:
| | 208/208/208
| | correspondence
Guidance | Differential thrust, manual control, straight-line following, and extensi-
| ble area planner | Manual and
| | semi-autonomous
| | operation
| | demonstrated; full area
| | coverage not
| | demonstrated
Heading | Maintain bow orientation through low-speed turns | Not satisfied with the
| | current GNSS +
| | six-axis IMU stack
Mapping | Produce a connected image sequence and later a metric orthomosaic | Connected transect
| | demonstrated; metric
| | orthomosaic not
| | demonstrated
Semantic sensing | Provide data structure for local debris annotation and model training | Dataset organization
| | implemented; trained
| | detector not yet
| | evaluated
Acoustic sensing | Explore receiver-chain information beyond a binary range threshold | Analog access concept
| | prepared; controlled
| | underwater dataset not
| | completed

Figure 2 summarizes the evidence hierarchy adopted throughout the paper. A capability is labelled field-demonstrated only when it appears in the raw mission data or source photographs. A capability can be described as implemented when it exists in supplied firmware but has not been validated in a complete mission. A planned capability is described only through an explicit protocol and expected metrics.

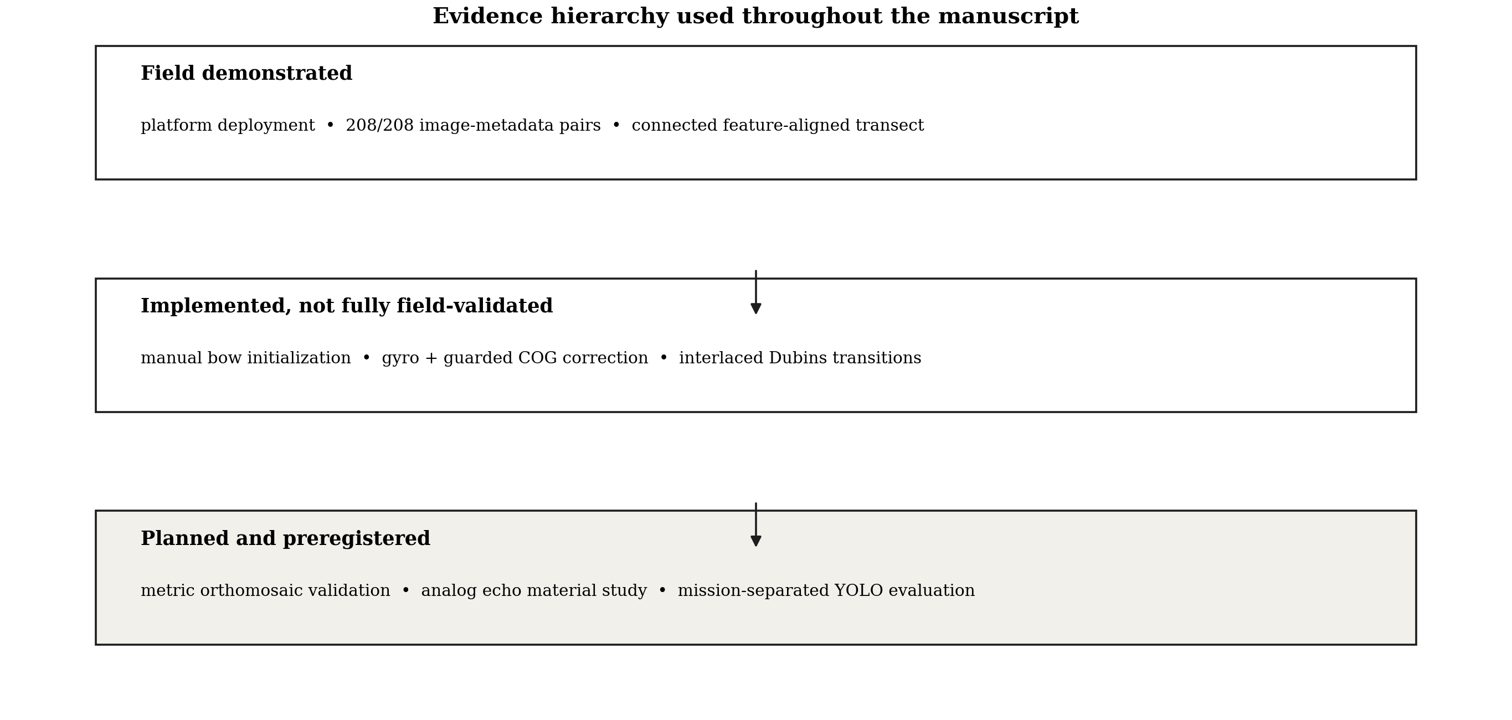
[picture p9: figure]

Figure 2: Evidence hierarchy used to separate field-demonstrated results, implemented but incompletely validated functions, and planned experiments.

### 4 Platform and Embedded Implementation

### 4.1 Mechanical platform and propulsion

DeepSeeker is a twin-hull surface craft with an overall length of 1130 mm and a beam of 800 mm. Two sealed PVC tubes provide buoyancy and support a reinforced wooden deck. The broad hull separation increases transverse stability and leaves a central region for the battery, control enclosure, and camera mounting. Two brushless underwater thrusters are installed at the stern and driven through independent electronic speed controllers. Equal thrust produces forward motion; a thrust difference produces yaw. A fixed bow fin was added during development to reduce lateral wandering and increase passive directional stability on straight segments.
The propulsion supply is 12 V. A regulated 5 V rail powers the controllers and sensors. The principal wiring is: GNSS TX to Main ESP32 GPIO16, GNSS RX from GPIO17, MPU-6050 SDA/SCL to GPIO21/22, left ESC signal to GPIO25, right ESC signal to GPIO2, sonar test lines to GPIO26/27, Main ESP32 TX/RX to the camera controller through GPIO14/13, and a common ground across all subsystems. The final paper does not present the prototype as optimized naval architecture. The mechanical design is a field-capable carrier whose purpose is to support sensor and autonomy experiments.

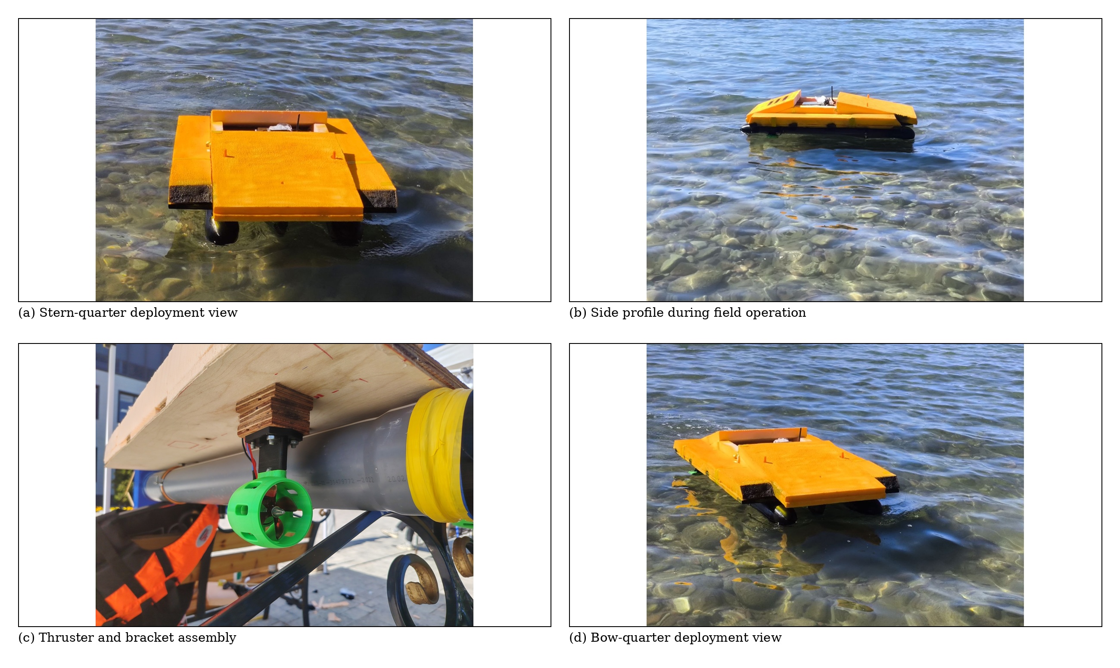
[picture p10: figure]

Figure 3: DeepSeeker as built and tested. The photographs are reproduced from the project archive without enhancement, background replacement, or synthetic modification.

### 4.2 Dual-controller architecture

The control architecture separates time-critical navigation from image encoding and storage. The Main ESP32 parses GNSS data, reads the MPU-6050, generates PWM commands for the two ESCs, executes the mission state machine, runs the path follower, and supervises failsafes. The ESP32-S3-CAM controls the OV3660 camera, writes JPEG files to microSD, stores metadata, and returns explicit capture acknowledgements.
This division addresses a practical embedded-systems problem. JPEG capture and SD-card writes can take hundreds of milliseconds and occasionally stall. If the same processor were responsible for motor output, navigation updates, web control, and image storage, a slow write could delay the control loop. The separated architecture contains this failure. The Main ESP32 can retain mission state and stop the vessel if the camera does not acknowledge a request, while the camera controller can reinitialize storage without blocking motor control. The camera configuration recorded in firmware and confirmed by the archive is QXGA JPEG at 2048 × 1536 pixels, JPEG quality setting 10, 20 MHz XCLK, and local microSD storage. At initialization, several frames are discarded so that exposure and white balance settle before mission capture. Data are stored in sequential mission folders. Each requested image is linked to a row in telemetry.csv and to a coordinate entry in geo.txt.

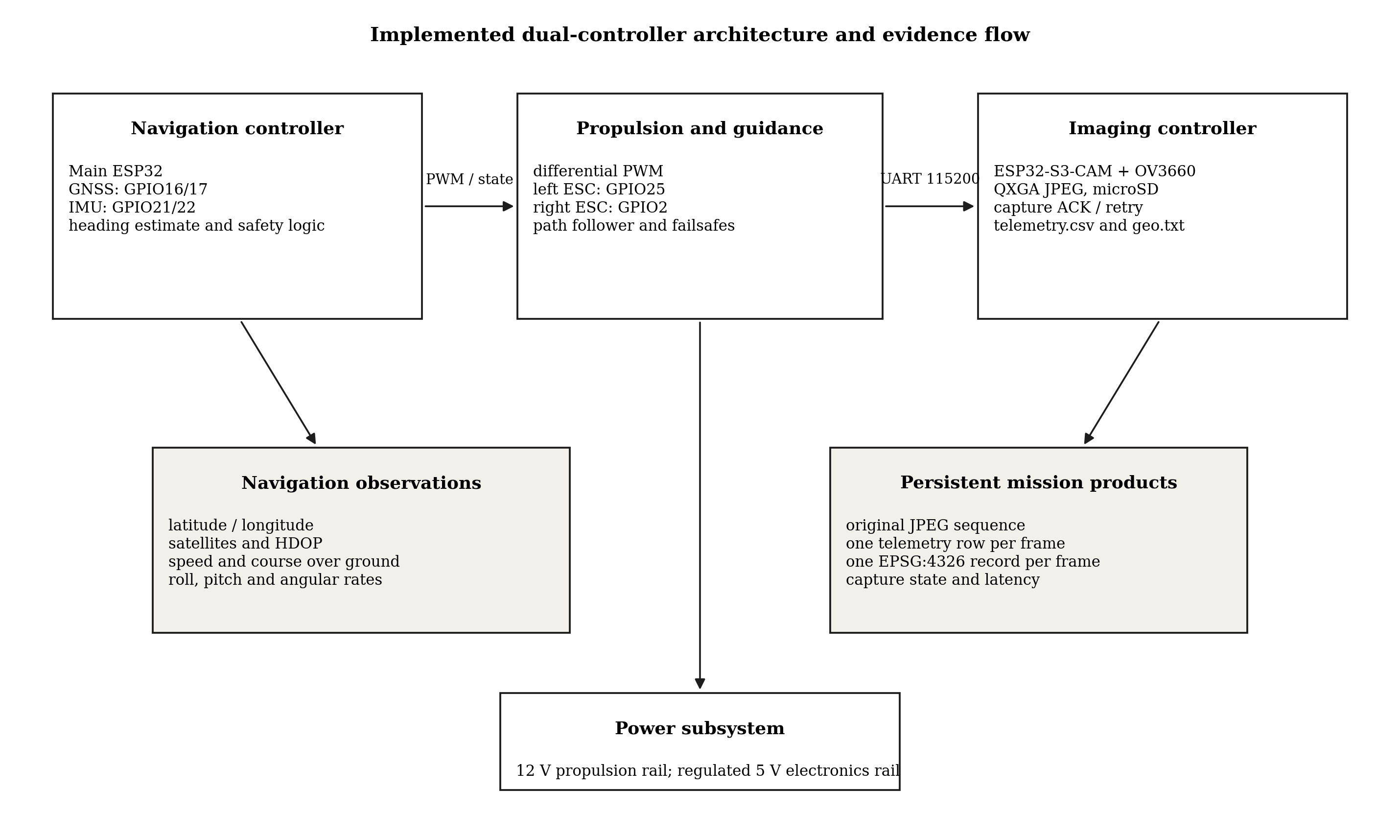
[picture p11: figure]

Figure 4: Implemented dual-controller architecture and evidence flow. Navigation and mission safety are separated from high-resolution image capture and persistent storage.

### 4.3 Capture transaction and fault containment

Communication between processors runs at 115200 baud. For each exposure, the Main ESP32 sends an image identifier and the current navigation state: UTC time, latitude, longitude, altitude, satellite count, HDOP, speed, GNSS course, roll, pitch, angular rates, total acceleration, and stability flags. The camera controller captures the image, writes the JPEG, appends a telemetry row, appends the geographic record, and returns one of three states: complete, partial, or error. Storage retry logic can reinitialize the SD card after a failure.
The transaction is deliberately auditable. A file count alone cannot establish data integrity because a frame may exist without a matching coordinate, or a metadata row may exist for a failed image. The one-to-one relationship in M0016 shows that the complete transaction was preserved for every requested frame. This is one of the strongest results of the prototype because it supports every later processing step.

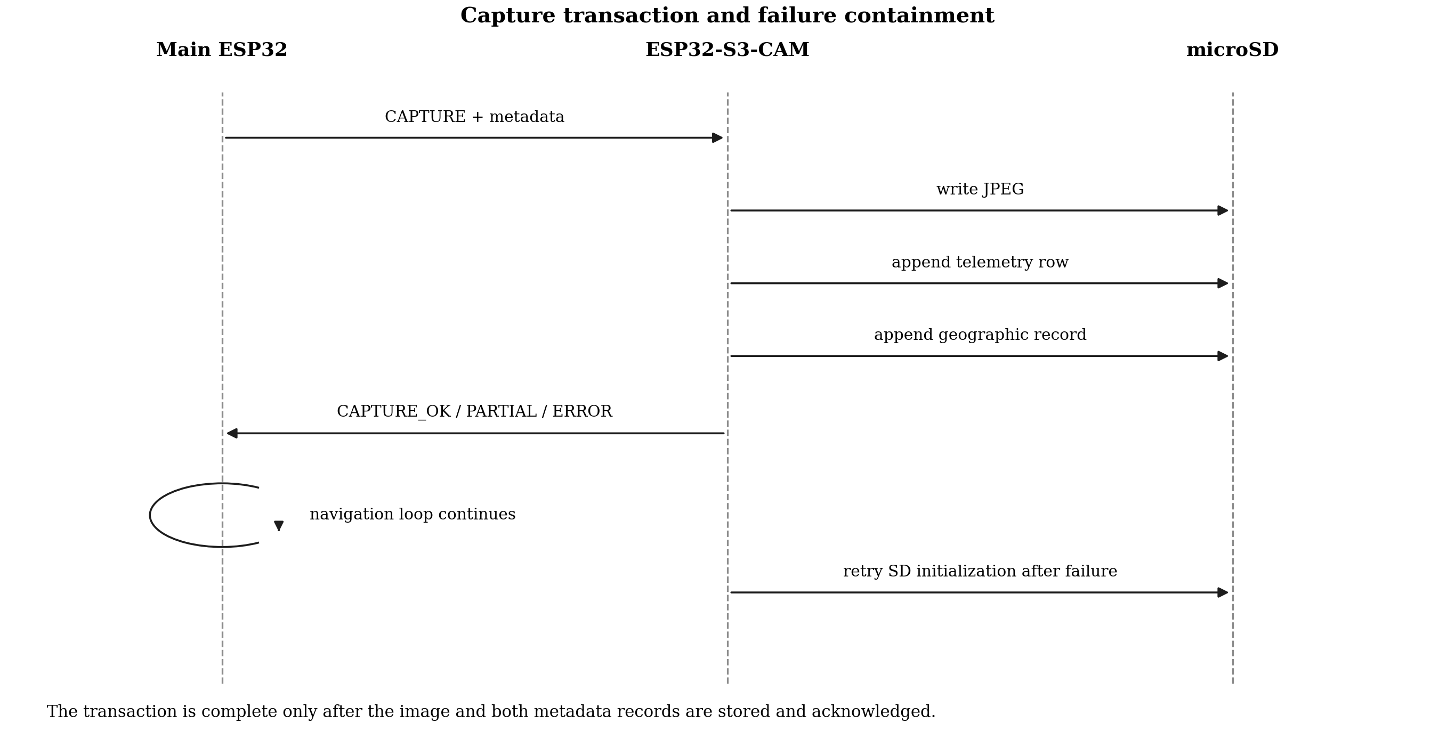
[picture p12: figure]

Figure 5: Capture transaction and failure containment. A request is considered complete only after the image and both metadata records are stored and acknowledged.

### 5 Navigation and Coverage Planning

### 5.1 Why the missing absolute heading matters

A surface vehicle has at least two different horizontal angles: bow heading ψ, describing the orientation of the hull, and course over ground χ, describing the direction of translational motion. These angles are similar only when sideslip and external disturbances are small. During wind, current, or asymmetric thrust, they can differ. More importantly, course over ground is undefined or unstable when the vessel is almost stationary.
The MPU-6050 provides a yaw rate ωz, not absolute yaw. After estimating a gyro bias bˆ
g, the heading can be
propagated as
ψˆ

k = wrap180 -ψˆ

k−1 + (ωz,k − bˆ
g)Δt
| . | (1)

Any residual bias accumulates. The firmware therefore uses a guarded complementary correction toward GNSS course over ground when speed, freshness, and plausibility conditions are satisfied:

ψˆ

k ← ψˆ

k + α wrap180 (χGNSS − ψˆ
k), | 0 < α ≪ 1. | (2)

This method can reduce drift on straight moving segments, but it cannot create an absolute orientation measurement during a low-speed pivot. It is a heading surrogate, not a full attitude solution.
Before a mission, the operator physically points the bow toward the first target and invokes a bow-lock routine. During the stationary interval, the code estimates gyroscope bias and accepts the geometric bearing to the first target as the initial heading. This procedure is practical for a prototype, but it means that the autonomy is operator-initialized. A rigorous description is therefore semi-autonomous or autonomy-capable, not fully autonomous.

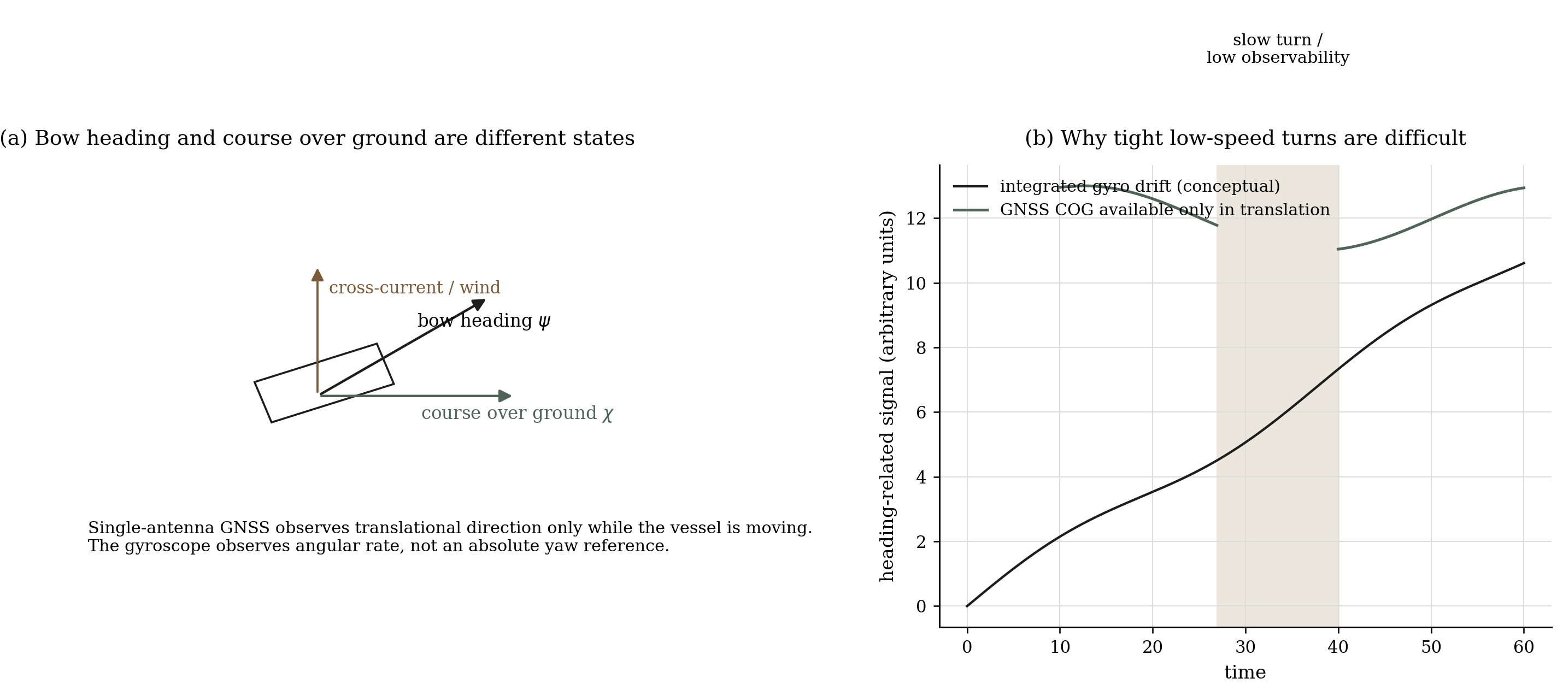
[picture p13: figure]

Figure 6: Heading observability. (a) Bow heading and course over ground represent different states under wind or cross-current. (b) A tight low-speed turn removes the translational information needed for GNSS course correction while gyro integration continues to drift.

### 5.2 Interlaced coverage and the teardrop transition

The intended survey mode is a set of parallel photographic strips inside a user-defined quadrilateral. Default strip spacing is 1.5 m, nominal capture interval is 1.1 s, and the default minimum turn radius is 2.0 m. The values are software defaults rather than validated physical optima. Strip spacing should eventually be derived from calibrated camera footprint and required side overlap; capture timing should be derived from speed and required forward overlap.
An adjacent-strip lawnmower pattern demands a nearly immediate reversal at the end of each line. For a small differential-thrust vessel, this can require one propeller to reverse or the boat to rotate almost in place. Such a manoeuvre slows the vessel, magnifies disturbance effects, and removes a reliable GNSS course. The project therefore implemented a wider external turn. The current strip is extended beyond the photographic region, the vessel follows a forward-only loop in an external headland, and it enters the next selected strip already aligned. The implementation is more rigorous than a manually drawn arc. For the end pose of the current strip and the entry pose of the next strip, the code evaluates the six canonical Dubins path families: LSL, RSR, LSR, RSL, RLR, and LRL. Each feasible candidate is discretized. Paths that re-enter the photographic rectangle are rejected, and the shortest remaining candidate is selected. The lane order is interlaced: even-indexed strips are visited first, followed by odd-indexed strips. This increases the lateral distance available between consecutively visited lines. The approach is physically plausible and consistent with current coverage-planning literature [5]. It is not yet a validated performance claim. The default radius must be measured against actual speed, battery voltage, loading, wind, and thrust asymmetry. A future comparison must quantify entry-heading error, cross-track error, transition time, minimum speed, energy use, and completion rate for pivot turns and several Dubins radii.

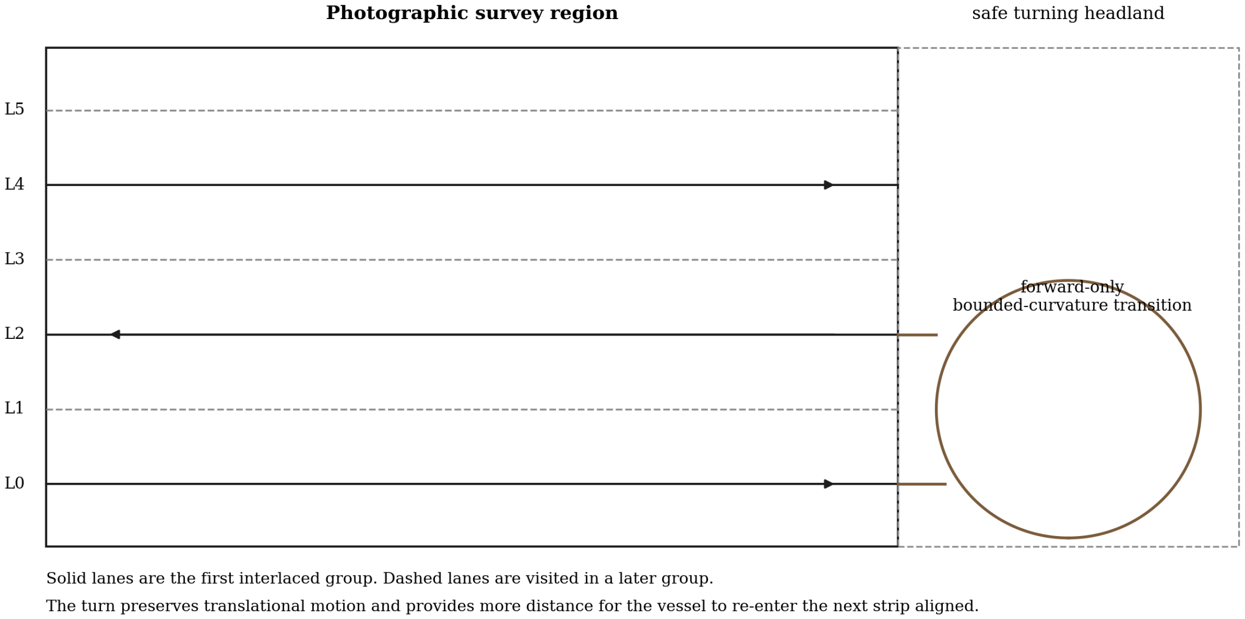
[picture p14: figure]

Figure 7: Implemented interlaced coverage concept. Solid lanes represent the first lane group; dashed lanes are visited later. The forward-only bounded-curvature turn is performed in a safe external headland rather than inside the photographic region.

### 6 Field Campaign and Analysis Methods

### 6.1 Mission M0016

Mission M0016 was conducted in shallow water at Lake Issyk-Kul on 17 July 2026. The raw archive contains 208 consecutively numbered JPEG files, 208 rows in telemetry.csv, and 208 entries in geo.txt. No image indices are missing. The first recorded exposure occurred at 03:41:25 UTC and the last at 03:46:04 UTC, giving an acquisition span of 279 s.
M0016 was an operator-assisted out-and-back image transect rather than a complete autonomous grid. That distinction is central to the interpretation. The mission is suitable for evaluating acquisition integrity, capture latency, GNSS behaviour, attitude, raw-image variability, and connected image registration. It is not suitable for measuring multi-strip coverage success or the performance of the implemented teardrop transition.

### 6.2 Trajectory processing

Latitude and longitude were converted to local east-north displacement using a small-area tangent approximation referenced to the first fix. Principal-component analysis was used descriptively to identify the dominant transect axis and estimate its span. PCA was not used as ground truth. The mission was divided into outbound frames 1–121, reversal frames 122–129, and return frames 130–208 based on the reversal in progression along the principal axis.
Summing point-to-point GNSS distances would overestimate travelled distance because metre-scale jitter is comparable to the separation between consecutive fixes. The analysis therefore reports bounding dimensions, principal-axis span, and the qualitative structure of the track instead of an apparent path length. Consecutive repeated coordinates were counted because they reveal frames captured before a new GNSS fix was available.

### 6.3 Image diagnostics

All image metrics were calculated from the original QXGA files without enhancement or recolouring. Grayscale standard deviation was used as a descriptive measure of contrast. Variance of the Laplacian was used as a descriptive edge-sharpness measure. Shannon entropy was used to describe texture information. These quantities are not universal underwater image-quality scores and do not directly measure photogrammetric accuracy. The supplied mosaic was evaluated as a connected visual product. Because the reconstruction code, detector and matcher settings, underwater calibration, control points, and independent scale were not part of the archive, the paper does not report ground-sampling distance, reprojection error, map accuracy, or registered-frame percentage. The product is described as a feature-aligned transect mosaic rather than an orthophoto.

### 7 Results

### 7.1 Complete acquisition and timing performance

The M0016 archive contains 208 images, and every image has a matching telemetry row and geographic record. This 208/208/208 correspondence is the primary systems result. It confirms that the two-controller transaction survived the entire field mission without losing the logical relationship between image and navigation data. Median capture latency was 445.5 ms. The 95th percentile was 516.6 ms, and the maximum was 1124 ms. JPEG size ranged from 81.8 to 120.1 KiB, with a median of 100.5 KiB. The UTC field has one-second resolution, so timing cannot be interpreted as a high-precision frame clock. Among 207 consecutive intervals, the median recorded gap was 1 s and the 95th percentile was 2.7 s. Thirty-four image pairs were recorded within the same UTC second, and five pauses lasted at least four seconds; the longest was 33 s. Sequence numbering remained continuous across the pauses.
These observations support two conclusions. First, local storage and explicit acknowledgements provided robust transactional logging. Second, the capture cadence was not uniform enough to be treated as a fixed frame rate. A future survey controller should trigger images by travelled distance and camera footprint rather than by a fixed timer alone.

### 7.2 Trajectory and GNSS behaviour

Median speed at image capture was 0.262 m s⁻¹

, the mean was 0.283 m s⁻¹ , and the 95th percentile was 0.628 m s⁻¹
. Satellite count remained between five and six. HDOP ranged from 1.55 to 2.35, with a median of
1.56. The local GNSS positions occupied a bounding box approximately 9.2 m east-west by 24.4 m north-south. The dominant principal axis spanned approximately 24.6 m, confirming that the mission was a long corridor rather than area coverage.
Figure 8 shows the capture positions reconstructed independently from the raw telemetry. The outbound and return passes are visibly separated, with a compact reversal at the far end. The median cross-axis separation between the two pass groups was approximately 4.1 m, but this value is derived from the same consumer GNSS and is not a surveyed lane-spacing measurement.

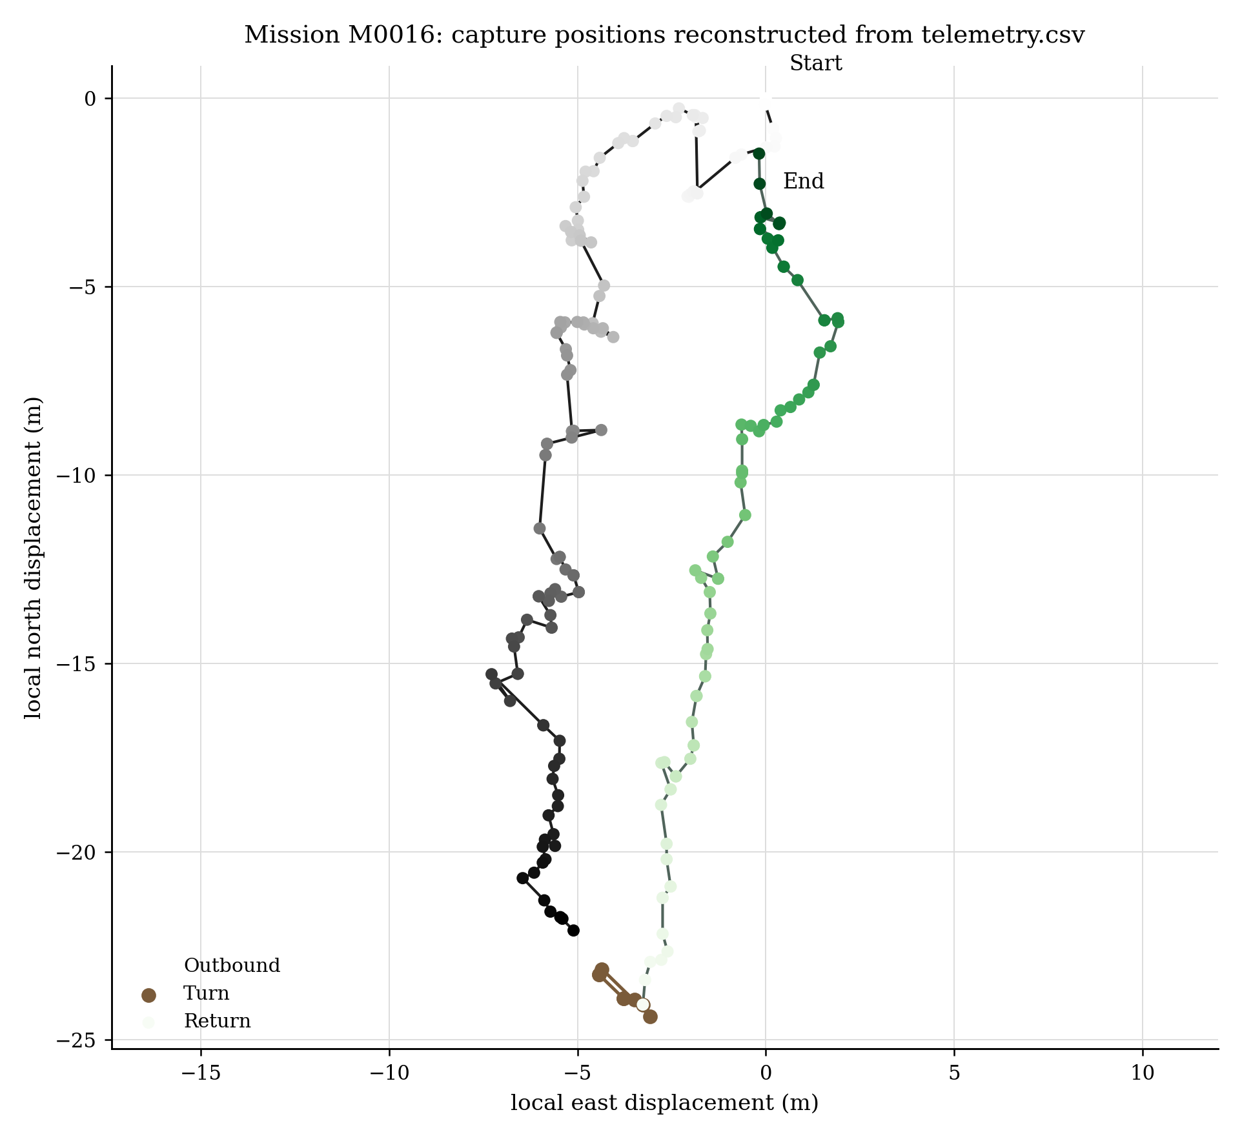
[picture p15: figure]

Figure 8: Mission M0016 capture positions reconstructed from telemetry.csv. Points are GNSS acquisition positions, not a surveyed ground-truth trajectory.

Two telemetry artefacts explain the navigation limitation more directly than the apparent track shape. First, 34 consecutive image pairs share identical latitude and longitude, showing that image capture sometimes occurred faster than GNSS position updates. Second, course_deg contains only one unique value, 115.24◦
, across all
208 rows. The physical track clearly reverses, so the field cannot represent a valid measured bow heading or an updated course for the mission. This stale or unrefreshed value removes the correction signal on which the magnetometer-free heading estimate depends.

### 7.3 Attitude and capture-state behaviour

All frames satisfied the firmware’s broad ±18◦ level criterion. Only 38.0% satisfied the stricter short-window stability flag. Median absolute roll was 0.51◦

, with a 95th percentile of 1.63◦
. Median absolute pitch was 1.93◦

, with a 95th percentile of 3.90◦
. The platform therefore remained within a moderate attitude envelope, but high-frequency motion often exceeded the stricter gyro and acceleration condition.
The firmware allowed deadline captures when waiting for a more stable state would risk losing overlap. This choice favoured sequence completeness over instantaneous sharpness. It was effective for acquisition integrity, but it should be studied explicitly in future work by relating the stability flag to keypoint count, inlier ratio, and registration failure.

### 7.4 Synchronized telemetry and visual conditions

Figure 9 shows speed, capture latency, roll and pitch, and standardized image diagnostics for the complete mission. The highlighted interval corresponds to the principal reversal. The speed trace confirms that the vehicle operated mainly in a low-speed regime. Capture latency remained near the median for most frames but included occasional spikes. Roll and pitch stayed moderate. Edge sharpness and gray-level contrast declined during the middle part of the sequence and recovered later.

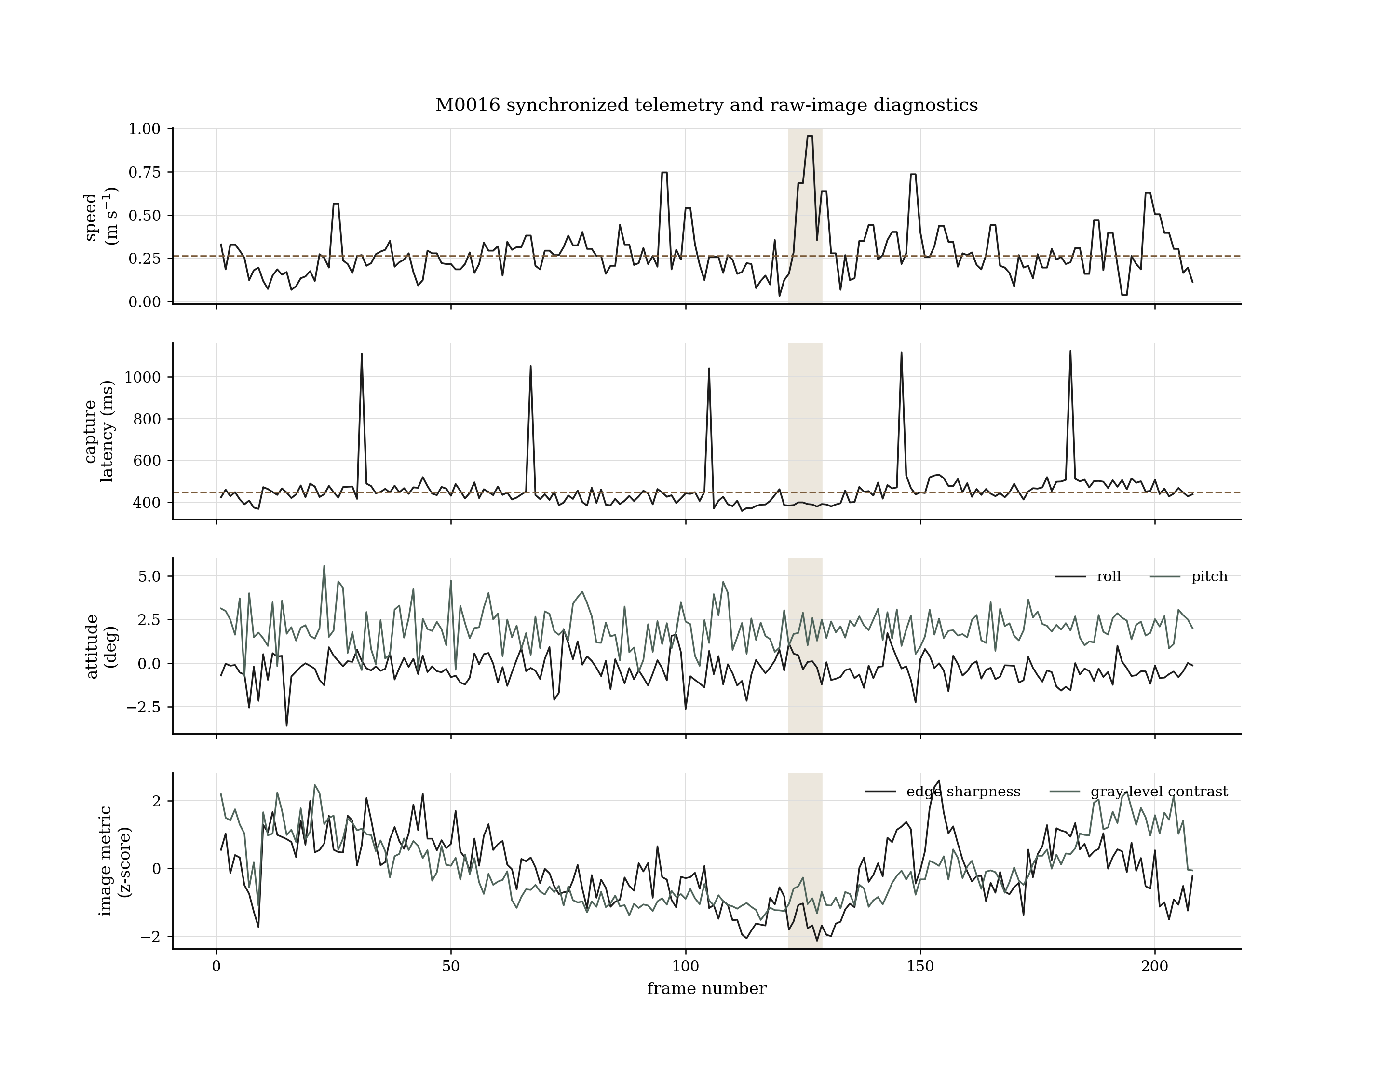
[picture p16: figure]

Figure 9: Synchronized telemetry and raw-image diagnostics for all 208 frames. The shaded interval contains the principal track reversal. Image metrics are standardized descriptive quantities, not calibrated mapping accuracy.

Full-resolution Laplacian variance had a median of 2.879 and ranged from 1.460 to 4.570 in the adopted OpenCV scale. Grayscale standard deviation had a median of 25.22 intensity levels and ranged from 11.13 to
55.12. Shannon entropy had a median of 6.530 bits and ranged from 5.376 to 7.361 bits. These values agree with direct visual inspection. Early frames show high-contrast cobbles and sunlight caustics. The middle portion contains smoother, lower-contrast sediment and weaker texture. Later frames recover coarser rock texture.

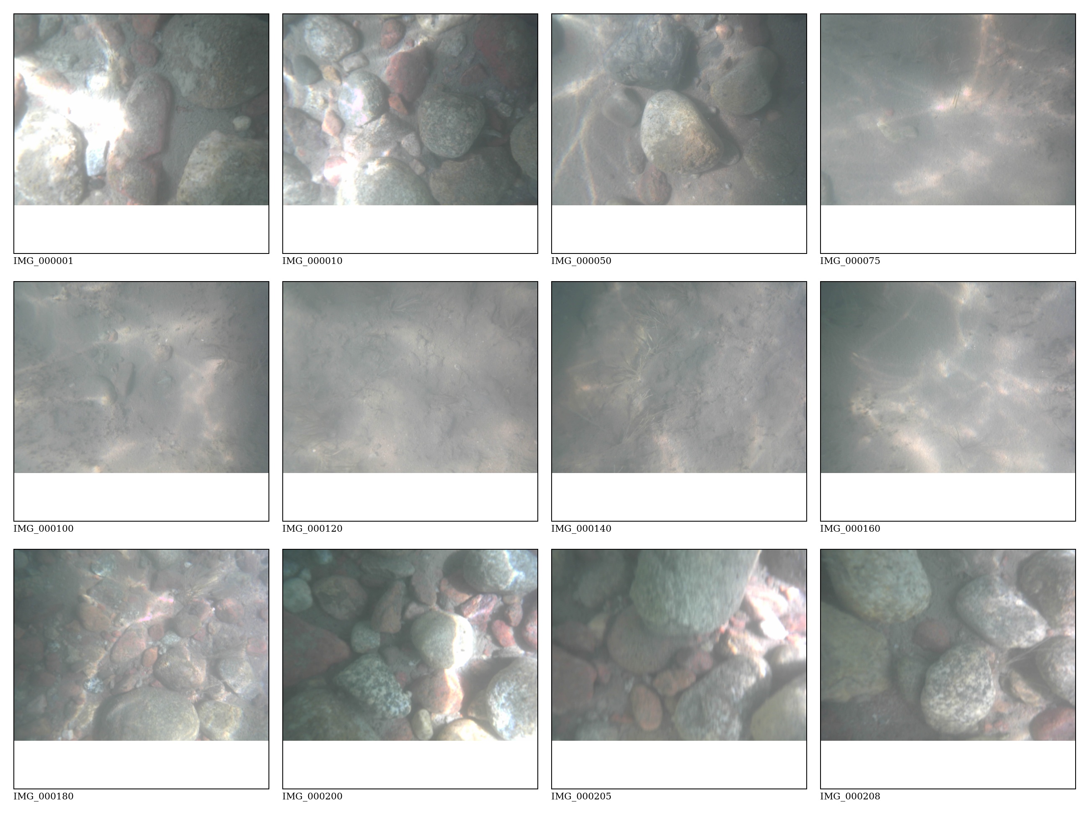
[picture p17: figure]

Figure 10: Representative original frames spanning the complete M0016 sequence. The panel shows the transition from coarse cobble texture to lower-contrast sediment and back to stronger rock texture.

### 7.5 Connected image registration

The supplied image product forms one connected visual transect. This is a meaningful field result: the sequence retained sufficient visual continuity to bridge a period of reduced texture and assemble a single corridor. The irregular external boundary and visible local distortion show that the product is not a finished map. No check points, independent scale, refractive camera calibration, or reconstruction log were supplied. Consequently, the manuscript does not claim metric orthorectification.
The original team diagnostic, connected mosaic, and raw/enhanced comparison are retained in source form in Figure 11. Enhancement improves local contrast and colour separation to the eye, but its contribution to registration is unknown. A controlled comparison must report keypoints, accepted matches, RANSAC inlier ratio, reprojection error, and connected-component count for raw and enhanced processing branches.

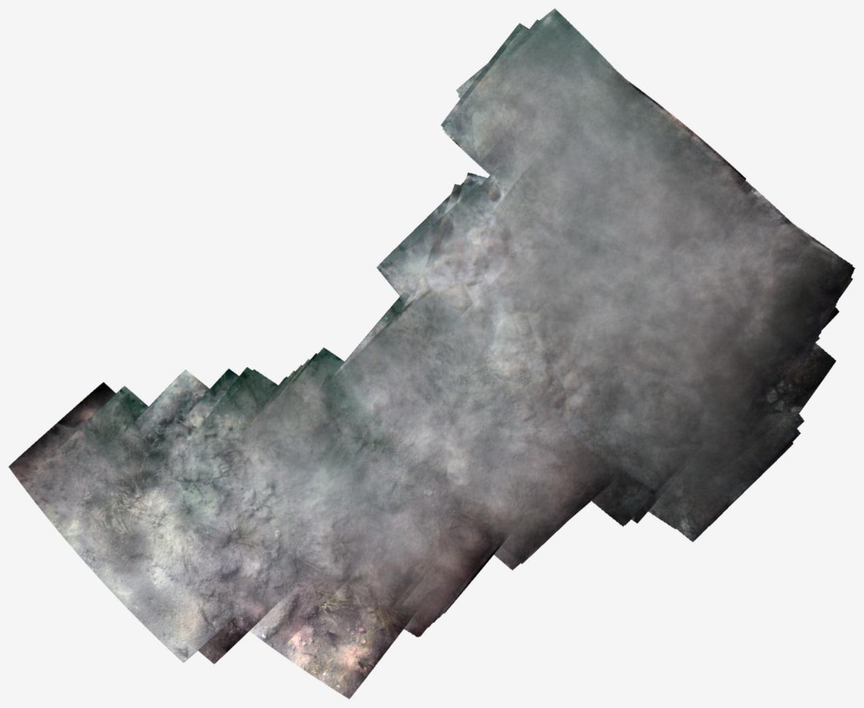
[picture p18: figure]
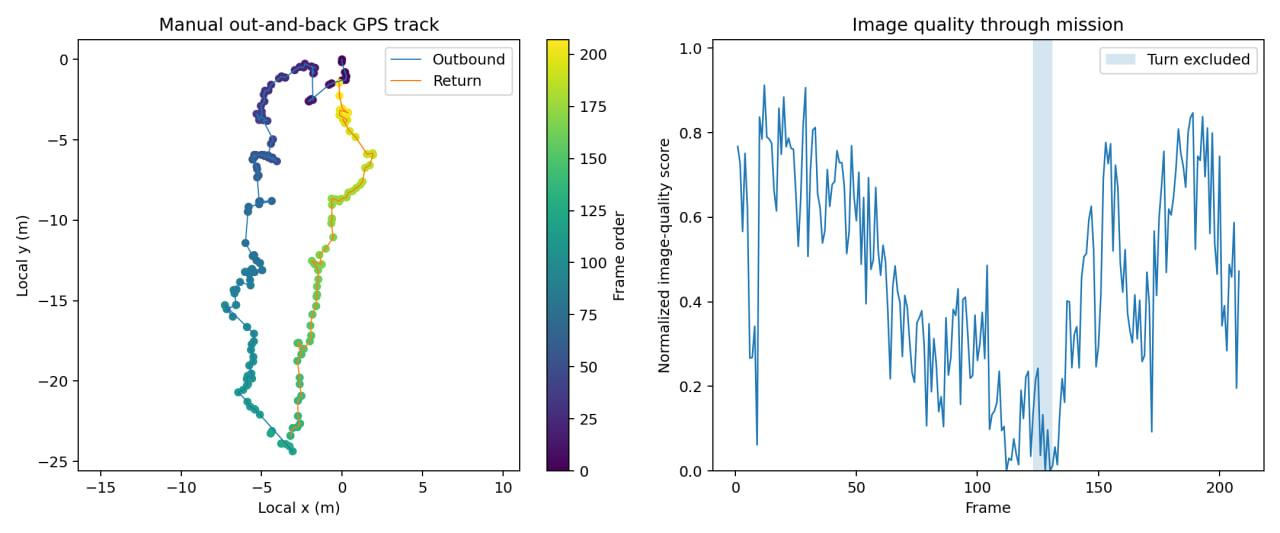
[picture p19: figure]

(a) Original track and image-quality diagnostic. | (b) Connected M0016 transect mosaic.

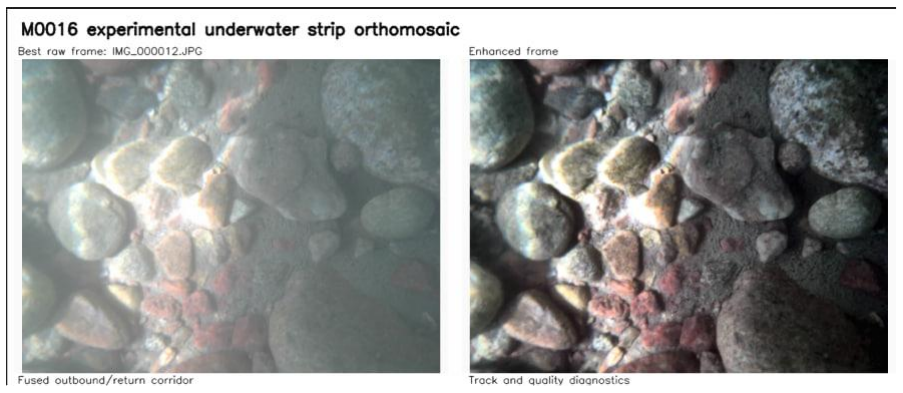
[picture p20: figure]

(c) Original raw/enhanced frame comparison.

Figure 11: Original mission outputs reproduced unchanged. They support a connected feature-aligned transect, not a metrically validated orthophoto.

Table 3: Quantitative summary of mission M0016.

Metric | Observed value
Complete image–telemetry–geotag triplets | 208 / 208 / 208
Acquisition span | 279 s
Image dimensions | 2048 × 1536 pixels
Median / mean / 95th-percentile speed | 0.262 / 0.283 / 0.628 m s⁻¹
GNSS satellites | 5–6, median 6
HDOP | 1.55–2.35, median 1.56
Median / 95th-percentile / maximum capture latency | 446 / 517 / 1124 ms
Median JPEG size | 100.5 KiB
Frames satisfying strict stability flag | 38.0%
Frames satisfying broad level criterion | 100.0%
Principal-axis span | 24.6 m
Repeated consecutive GNSS fixes | 34 pairs
Unique values in logged course field | 1
Connected supplied image product | 1 feature-aligned transect

### 8 Discussion

### 8.1 The strongest contribution is acquisition integrity

The platform’s clearest success is the complete synchronized archive. Every requested image has a matching navigation row and coordinate record. For an ESP32-class field system, this is not a trivial administrative detail. It demonstrates that high-resolution capture, SD-card storage, motor control, and mission logging were separated effectively enough to survive the full run. The architecture gives future experiments a reliable data foundation. Better GNSS, a new camera, an altimeter, or a semantic detector can be evaluated only if the underlying mission record remains complete.
This result also changes how affordability should be discussed. The scientific advantage is not simply that inexpensive components were used. It is that the system is inspectable, repairable, and organized around explicit transactions. A locally maintainable architecture can remain less expensive than a commercial survey platform while still adopting a better GNSS receiver, dual-antenna heading, calibrated optics, and a true underwater altimeter.

### 8.2 The central failure is state observability, not software complexity

The repeated development difficulty is often summarized as “there was no compass.” A more precise statement is that the system lacked an absolute yaw observation during the manoeuvres in which heading mattered most. This is a deeper result. The gyroscope supplied angular rate and the GNSS supplied approximate position, but neither supplied a stable bow direction at low speed. The stale course field in M0016 provides direct evidence that the correction pathway was unavailable in the field data.
This finding explains why a complete lawnmower route could not be recovered merely by writing more code. A path planner can generate a mathematically valid route, and a controller can calculate a desired heading, while the state estimator remains unable to determine the actual heading. Adding control gains, waypoints, or more complex logic cannot remove this ambiguity. The next version should therefore prioritize sensing before controller complexity.
A dual-antenna GNSS heading solution is particularly attractive because it can provide absolute orientation without translational speed and is less vulnerable than a magnetometer to currents and magnetic materials near the propulsion system. A carefully mounted and calibrated nine-axis IMU is a lower-cost alternative, but its placement, hard-iron calibration, soft-iron calibration, and dynamic validation must be reported. RTK positioning is a separate upgrade: it improves position but does not by itself solve bow heading unless the receiver uses an antenna baseline.

### 8.3 Why the external turn remains a strong research direction

The implemented teardrop transition is a sound response to the interaction between vehicle dynamics and navigation sensing. A pivot turn is spatially compact but creates the worst conditions for course-over-ground correction. A broad forward-only turn takes more space but keeps the craft moving, avoids a motor reversal, and allows the hull to settle before it reaches the next image line. The planner’s enumeration of all six Dubins families and rejection of paths that cross the photographic region are technically meaningful features.
The current paper deliberately stops before claiming that the turn improves performance. That claim requires a repeated field comparison. The minimum radius should not be selected by intuition alone. It should be measured as a function of forward command, differential command, battery voltage, payload, and wind. A strong experiment would compare a pivot, a conventional close U-turn, and several bounded-curvature radii. Outcomes should include actual radius, entry-heading error, cross-track error over the first metres of the next strip, minimum speed, transition duration, energy, and success rate. The safe headland must also be defined as a physical obstacle-free polygon, not merely as empty space outside the image region.

### 8.4 The visual result is credible because the claim is narrow

M0016 supports connected underwater mosaicking. It does not support a metric orthophoto. This distinction is essential. A visually coherent image can contain scale drift, local warping, and systematic refractive error. The current output is useful for qualitative inspection and for demonstrating overlap, but it cannot yet provide defensible object coordinates or area measurements.
A metric experiment needs underwater calibration in the final housing, a rigid camera mount, known scale bars or surveyed bottom targets, a measured camera-to-bottom distance, and a fully documented reconstruction pipeline. The pipeline should report detector, descriptor, matching rule, geometric model, RANSAC threshold, accepted-frame fraction, inlier ratio, and reprojection error. Check-point RMSE should be reported separately from fit error. Only after those measurements should the term orthomosaic be used.
The timing data also suggest an algorithmic improvement. At the median speed and 1.1 s nominal interval, the vessel travels about 0.29 m between requested exposures. That number is meaningful only if camera footprint and bottom distance are known. A better trigger computes the desired along-track step from footprint L f and forward overlap O f

:

Δx = L f (1 − O f ), | T =

Δx

v

. | (3)

The line spacing should be calculated similarly from cross-track footprint and side overlap. This makes the acquisition geometry adapt to speed and altitude rather than relying on fixed time and distance defaults.

### 8.5 YOLO and acoustic classification are future experiments, not decorative features

The project is structurally prepared for local object detection because every frame belongs to a named mission and carries acquisition metadata. That is useful, but it is not model performance. A defensible dataset should use retrievable targets, define classes before annotation, and split data by mission or site. Adjacent frames must not be divided randomly across train and test sets because they contain nearly identical scenes. Public underwater datasets can initialize the model, but the final evaluation must use unseen Issyk-Kul missions and report precision, recall, mAP50, mAP50–95, inference speed, and failure modes by visibility condition.
The analog ultrasonic branch is similarly promising only under a narrow hypothesis. Accessing the receive chain before the module’s binary threshold may reveal waveform or envelope features. Echo amplitude can depend on acoustic impedance, but also on distance, angle, target size, roughness, coupling, bubbles, temperature, and gain. A single analog voltage cannot identify material. The correct experiment holds geometry constant, tests repeated targets at several ranges and angles, extracts time of flight, peak amplitude, energy, width, and spectral features, and evaluates classifiers with complete range-angle groups held out. A negative result remains scientifically useful if within-class variability exceeds between-material separation.

### 8.6 Broader significance for locally developed robotics

The domestic contribution of DeepSeeker is not a claim that imported components became a wholly indigenous sensor. The contribution is that mechanical integration, wiring, communication protocol, mission logic, field workflow, and failure diagnosis were carried out by the team in Kyrgyzstan. This creates local engineering capability and a platform that can be repaired and extended without replacing the entire system.
For other student and early-stage robotics teams, the paper offers a general lesson. A sophisticated route planner does not compensate for an unobservable state. A connected mosaic does not prove orthorectification. A GPS coordinate attached to a frame does not equal the coordinate of an object on the bottom. A prepared annotation workflow does not prove neural-network accuracy. Keeping these layers separate produces a stronger paper because every claim can be traced to a specific experiment.

### 9 Preregistered Validation Programme

The next campaign should be designed as a sequence of controlled studies rather than as another general demonstration. Each study should isolate one uncertainty and preserve the original data required for independent

reanalysis.

### 9.1 Navigation and turn validation

A rectangular test area should be established with independently surveyed reference points. At least five straight-line trials and five turns should be completed for each heading configuration: gyro propagation after bow lock, gyro plus guarded GNSS course correction, calibrated magnetometer, and dual-antenna heading if available. Pivot turns should be compared with bounded-curvature radii of 1.5, 2.0, 2.5, and 3.0 m at several forward commands. Primary outcomes are cross-track RMSE, 95th-percentile cross-track error, entry-heading error, minimum speed, transition time, path length, battery energy, and completion rate.

### 9.2 Metric optical survey

The camera should be calibrated underwater in the final housing. Focus and camera-to-port position must remain fixed. Scale bars and independent check points should be placed on the bottom. Longitudinal trigger distance and strip spacing should be computed from the calibrated footprint and target overlaps. At least three complete grids should be repeated under comparable conditions. The analysis should report registered-image fraction, connected components, tie-point inlier ratio, median reprojection error, check-point RMSE, ground-sampling distance, and uncovered-area fraction.

### 9.3 Analog echo-signature study

The analog tap should be buffered and protected before ADC sampling. Equal projected-area targets of aluminium or steel, PVC, waterlogged wood, and stone should be tested at 0.30, 0.50, 0.75, and 1.00 m and at incidence angles of 0◦

, 15◦

, and 30◦
. At least 20 repetitions per cell are required. Water temperature, target dimensions, turbidity, gain, and mounting geometry must be recorded. Features should include time of flight, peak amplitude, integrated energy, pulse width, rise time, decay time, and frequency-band energy where sampling permits. Evaluation should hold out complete range-angle groups.

### 9.4 Local debris detector

Only retrievable, non-polluting targets should be deployed. Initial classes may include plastic container, metal-like debris, wood, rope or textile, and natural stone/background. Data should span several missions, bottom types, depths, and visibility conditions. Train, validation, and test partitions should be separated by mission or site. Results should report class counts, annotation policy, precision, recall, mAP50, mAP50–95, confusion matrix, inference speed, and performance stratified by depth and visibility.

Table 4: Minimum next-stage validation matrix.

Experiment | Controlled variables | Primary outcomes
Straight-line guidance | Heading source, speed command, wind, pay-
| load | Cross-track RMSE, 95th-percentile error, com-
| | pletion rate
Turn comparison | Pivot vs. 1.5–3.0 m radii, command level,
| battery state | Actual radius, entry-heading error, minimum
| | speed, energy, success
Complete grid | Strip spacing, overlap, heading source, camera
| height | Coverage gaps, registered-frame fraction, mis-
| | sion duration, map geometry
Underwater calibration | Housing geometry, focus, calibration target | Intrinsics, refractive parameters, reprojection
| | residuals
Echo signatures | Material, distance, angle, temperature, gain | Macro-F1, balanced accuracy, confusion ma-
| | trix, uncertainty
Debris detection | Class, mission, visibility, depth, bottom type | Precision, recall, mAP, inference speed,
| | domain-shift failure

### 10 Limitations

The current evidence is based on one deeply analysed mission. M0016 provides a complete archive, but one mission cannot establish general reliability across wind, wave, depth, lighting, and turbidity conditions. The GNSS track is not independent ground truth, so cross-track accuracy and pass separation cannot be validated metrically. The supplied mosaic lacks reconstruction logs, underwater calibration, and check points. The implemented coverage planner was inspected in firmware but not evaluated in a complete grid. The acoustic and neural-network branches remain protocols rather than results.
The manuscript also avoids several tempting but unsupported claims. RGB imagery cannot determine heavy-metal concentration. A surface GNSS coordinate is not the exact coordinate of an object on the bottom. A waterproof ultrasonic range module is not automatically a bathymetric sounder. A connected image mosaic is not automatically an orthophoto. These limitations define the present scope and protect the credibility of the measured results.

### 11 Conclusion

DeepSeeker demonstrates that a locally developed, resource-constrained catamaran can collect a complete synchronized underwater image archive during a real shallow-water mission. M0016 produced 208 QXGA images, 208 telemetry rows, and 208 geographic records over 279 s. Median capture latency was 446 ms, median speed was 0.262 m s⁻¹
, and the sequence produced one connected feature-aligned transect. These results establish acquisition integrity and field readiness of the embedded architecture.
The same archive identifies the decisive obstacle to full area coverage. The logged course did not update through the physical reversal, and the six-axis IMU provided no absolute yaw reference. The system could therefore propagate heading on straight moving segments but could not guarantee bow orientation during a compact low-speed turn. This is a state-observability problem rather than a shortage of software logic.
The supplied firmware contains a credible geometric response: manual initial heading, gyro propagation, guarded GNSS correction, interlaced lane ordering, and forward-only bounded-curvature transitions. The next step is not to describe this implementation more confidently. It is to validate it against pivot turns, independent position and orientation reference, repeated missions, and explicit metrics.
The project is competitive when positioned accurately. It is not yet a replacement for mature hydrographic or photogrammetric platforms. It is a complete, inspectable, locally maintainable experimental system that has already produced a high-quality raw field dataset and a clear engineering diagnosis. By preserving the evidence boundary and preregistering the next experiments, DeepSeeker provides a rigorous foundation for precise coverage guidance, calibrated shallow-water mapping, mission-separated debris detection, and controlled acoustic research at Lake Issyk-Kul.

Data and Code Availability

The analysed field archive is mission M0016 and contains 208 original JPEG images, telemetry.csv, and geo.txt. The firmware examined for this manuscript includes the Main ESP32 autonomy code with interlaced bounded-curvature planning and the ESP32-S3-CAM mission-logging code. A public release should preserve original files, checksums, reconstruction scripts, calibration files, and a machine-readable description of later annotations.

Acknowledgements

The authors thank the Young Scientists Camp organizers, project mentors, and participants who supported construction and field testing at Lake Issyk-Kul.

References

[1] UNESCO. Issyk-Kul Biosphere Reserve. Man and the Biosphere Programme. Accessed July 2026.
[2] Guo R, Wu J, Zhang H, Li Q. History of organic pollution in montane Lake Issyk-Kul, Kyrgyzstan, Central Asia, inferred from a sediment core. Environmental Research. 2024;250:118505.
[3] Choset H. Coverage for robotics—A survey of recent results. Annals of Mathematics and Artificial Intelligence. 2001;31:113–126.
[4] Galceran E, Carreras M. A survey on coverage path planning for robotics. Robotics and Autonomous Systems. 2013;61(12):1258–1276.
[5] Sudha SKR, Mishra D, Hameed IA. A coverage path planning approach for environmental monitoring using an unmanned surface vehicle. Ocean Engineering. 2024;310:118645.
[6] Cocchi L, Muccini F, Locritani M, Spinelli L, Cocco M. CORAL—Catamaran for Underwater Exploration: Development of a Multipurpose Unmanned Surface Vessel for Environmental Studies. Sensors. 2024;24(14):4544.
[7] Raber GT, Schill SR. Reef Rover: A Low-Cost Small Autonomous Unmanned Surface Vehicle for Mapping and Monitoring Coral Reefs. Drones. 2019;3(2):38.
[8] Gogendeau P, Bonhommeau S, Fourati H, Julien M, Contini M, Chevrier T, Nieblas AE, Bernard S. An autonomous surface vehicle for acoustic tracking, bathymetric and photogrammetric surveys. Ocean Engineering. 2025;331:121201.
[9] Jordt-Sedlazeck A, Koch R. Refractive structure-from-motion on underwater images. In: Proceedings of the IEEE International Conference on Computer Vision; 2013. p. 57–64.
[10] Shortis M. Calibration techniques for accurate measurements by underwater camera systems. Sensors. 2015;15(12):30810–30826.
[11] Massot-Campos M, Oliver-Codina G. Optical sensors and methods for underwater 3D reconstruction. Sensors. 2015;15(12):31525–31557.
[12] Ðuraš A, Wolf BJ, Ilioudi A, Palunko I, De Schutter B. A dataset for detection and segmentation of underwater marine debris in shallow waters. Scientific Data. 2024;11:921.
[13] Hong J, Fulton M, Sattar J. TrashCan: A semantically-segmented dataset toward visual detection of marine debris. arXiv:2007.08097. 2020.
[14] Fulton M, Hong J, Islam MJ, Sattar J. Robotic detection of marine litter using deep visual detection models. In: Proceedings of the IEEE International Conference on Robotics and Automation; 2019. p. 5752–5758.
[15] u-blox AG. NEO-6 GPS Modules Data Sheet, document GPS.G6-HW-09005-E. 2011.

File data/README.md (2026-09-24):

# Field datasets

This directory preserves the two mission datasets used for the main diagnostic and final result.

## M0014

- 362 JPEG images at 2048 x 1536.
- Complete `telemetry.csv` and OpenDroneMap-compatible `geo.txt`.
- Important diagnostic run: the acquisition system worked, but optical softness and haze prevented reliable stitching.
- The derived directory contains per-frame metrics, contact sheets, enhancement comparisons, and the failed stitching diagnostic.

## M0016

- 208 JPEG images with complete telemetry.
- One manually controlled outbound-and-return transect.
- Strongest field result and source of the connected corridor mosaic.
- The derived directory contains image-quality metrics, route diagnostics, frame selection, pushbroom-style strips, and feature-aligned results.

## Directory policy

```text
M00xx/
  raw/       immutable archive from the field card
  source/    extracted telemetry and geo files for easy inspection
  derived/   metrics, figures, mosaics, and method notes
```

Do not replace raw archives with processed files. New processing results should state the input checksum, software version, parameters, and limitations.

The raw archives use Git LFS. Run `git lfs install` before cloning or committing this repository.

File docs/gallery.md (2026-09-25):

# Field gallery

The photographs below show the completed DeepSeeker hull operating in the shallow nearshore water of Lake Issyk-Kul. They are unretouched field photographs from the project archive.

DeepSeeker side profile on the water

DeepSeeker front view

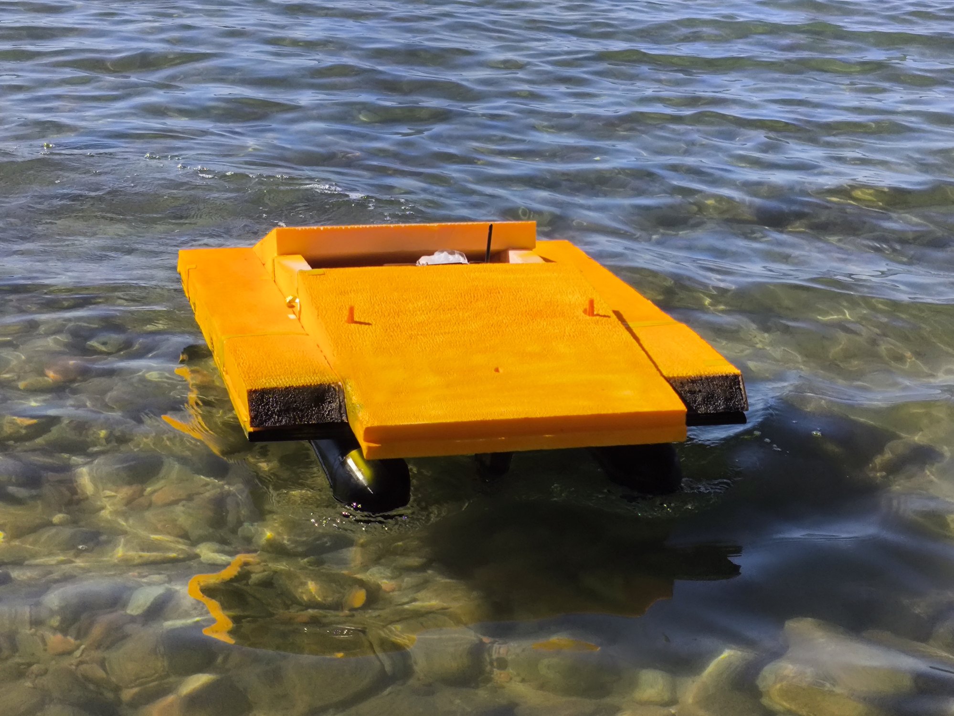
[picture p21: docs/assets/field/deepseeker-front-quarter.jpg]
DeepSeeker front-quarter view


DeepSeeker wider front-quarter view

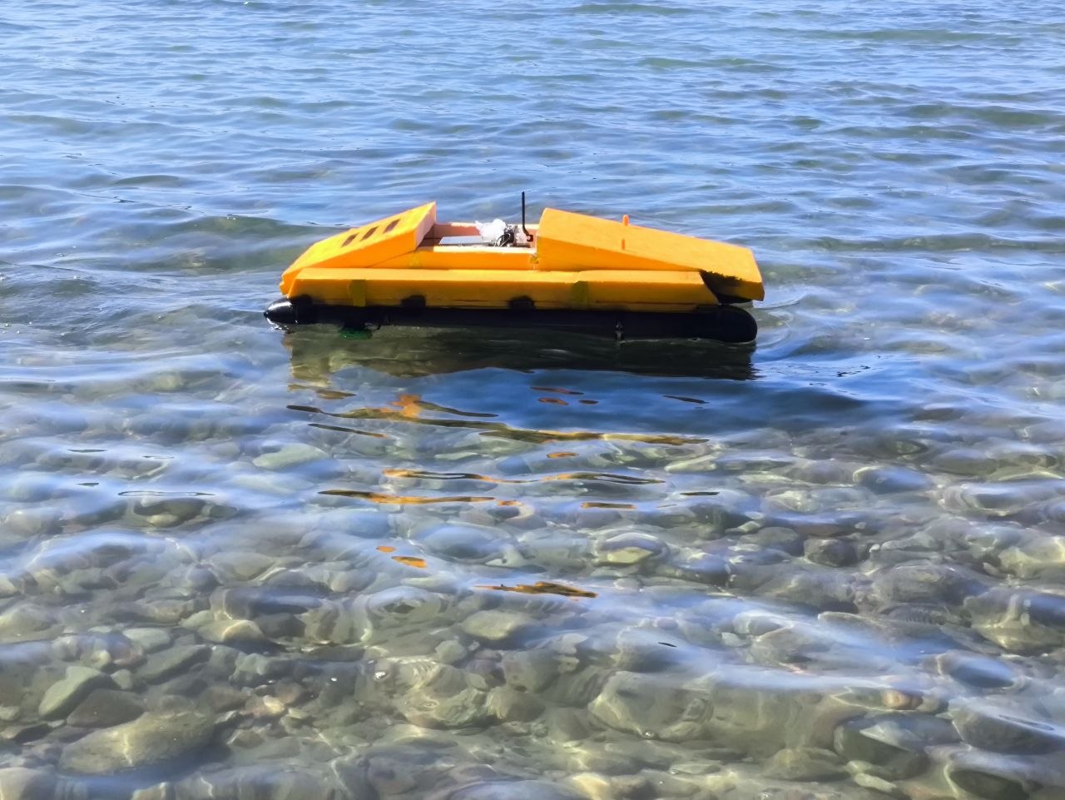
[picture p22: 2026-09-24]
docs/assets/boat-side.jpg

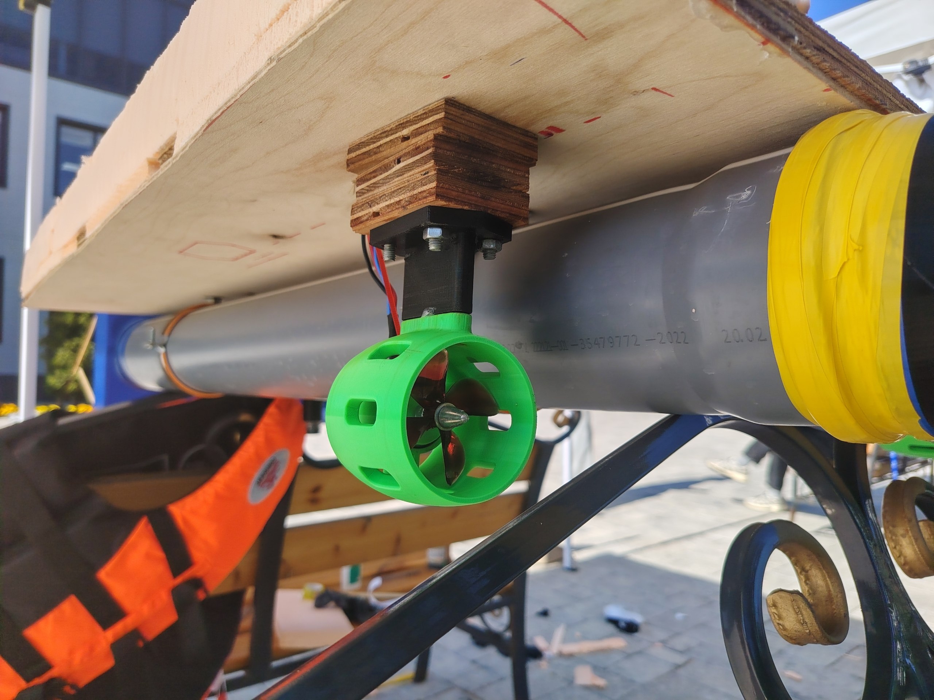
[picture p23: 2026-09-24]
docs/assets/thruster.jpg

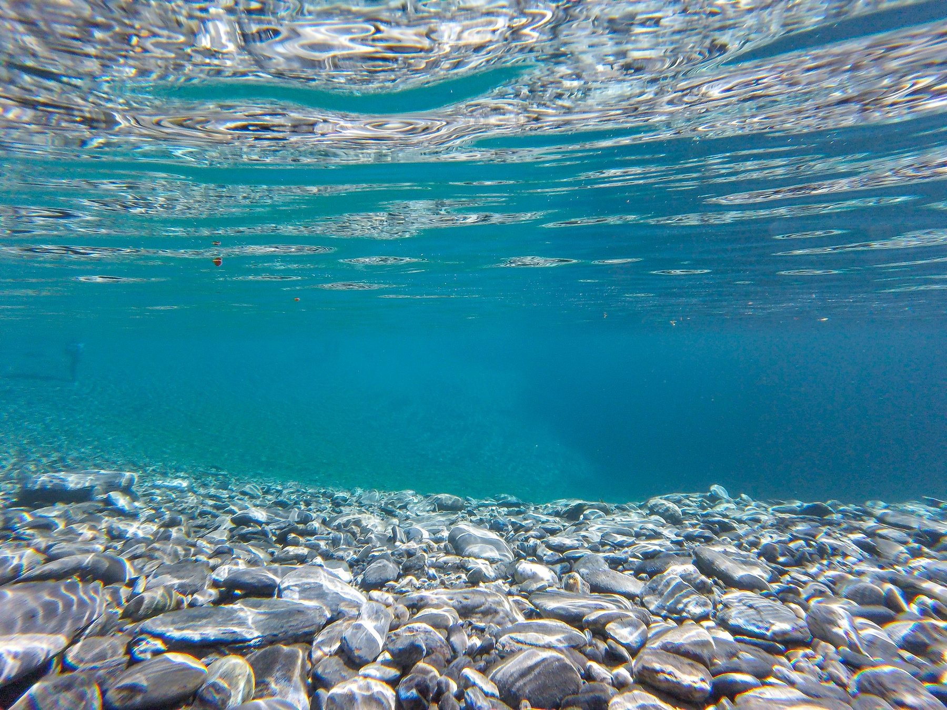
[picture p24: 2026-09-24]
docs/assets/underwater-blue.jpg

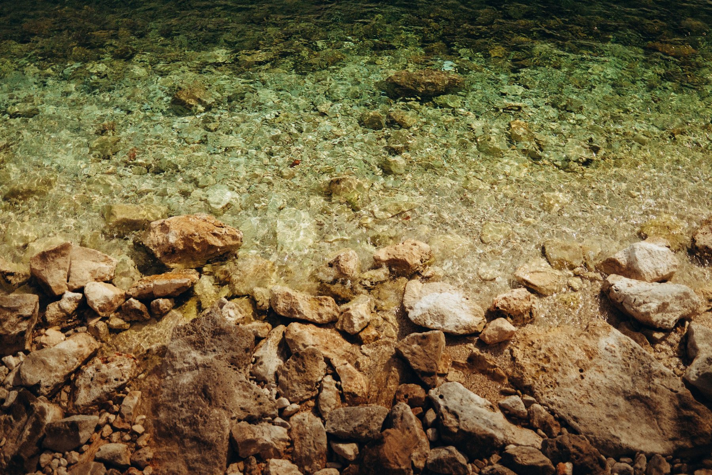
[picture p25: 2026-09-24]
docs/assets/shoreline-clear.jpg

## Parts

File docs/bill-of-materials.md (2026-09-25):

# Recovered bill of materials

This list describes the hardware that can be confirmed from the final firmware, photographs, purchase records, and surviving project files. Exact part numbers are left blank where the camp record does not support a confident claim.

| Subsystem | Recovered component | Status in final system |
| --- | --- | --- |
| Main controller | ESP32 development board | Motor control, GNSS, IMU, mission logic, and Wi-Fi control page |
| Camera controller | GOOUUU ESP32-S3-CAM V1.5 | Camera, PSRAM, microSD, and mission storage |
| Camera | OV3660 | Downward-looking JPEG capture |
| Positioning | GY-NEO6MV2 / NEO-6M-class GNSS module | UART position, speed, course, satellites, and HDOP |
| Inertial sensing | GY-521 MPU-6050 | Roll, pitch, angular rate, and stability diagnostics |
| Storage | microSD card | Numbered mission folders, JPEG, `telemetry.csv`, and `geo.txt` |
| Propulsion | Two electric underwater thrusters | Differential thrust |
| Motor control | Two bidirectional ESCs | 1500 us neutral; lower pulse commanded forward on the tested boat |
| Structure | Twin-pontoon catamaran hull with orange upper body | Surface platform and electronics enclosure |
| Power | Traction battery and regulated controller supply | Exact battery and regulator model not recovered |
| Long-range radio experiment | NRF24L01 PA/LNA module and external antenna hardware | Purchased and evaluated, not part of the final validated data path |
| Sonar experiment | Waterproof ultrasonic transducer and analog amplifier | Experimental; not used to support the final mapping result |

## Confirmed controller wiring

| Signal | Pin |
| --- | ---: |
| Left ESC | GPIO25 |
| Right ESC | GPIO2 |
| GPS RX from module TX | GPIO16 |
| GPS TX to module RX | GPIO17 |
| MPU-6050 SDA | GPIO21 |
| MPU-6050 SCL | GPIO22 |
| Main TX to camera RX | GPIO14 to S3 GPIO1 |
| Main RX from camera TX | GPIO13 from S3 GPIO2 |

Full electrical and power notes are in [`hardware.md`](hardware.md). Camera and SD pin definitions remain in the camera firmware because they are specific to the tested ESP32-S3-CAM board.

## Still missing from the archive

- Battery chemistry, capacity, and connector specification.
- Exact ESC and thruster commercial model numbers.
- Measured hull dimensions and mass.
- A final wiring-diagram drawing separate from the source-code pin table.

These fields should be measured from the surviving vehicle before a hardware revision is published.

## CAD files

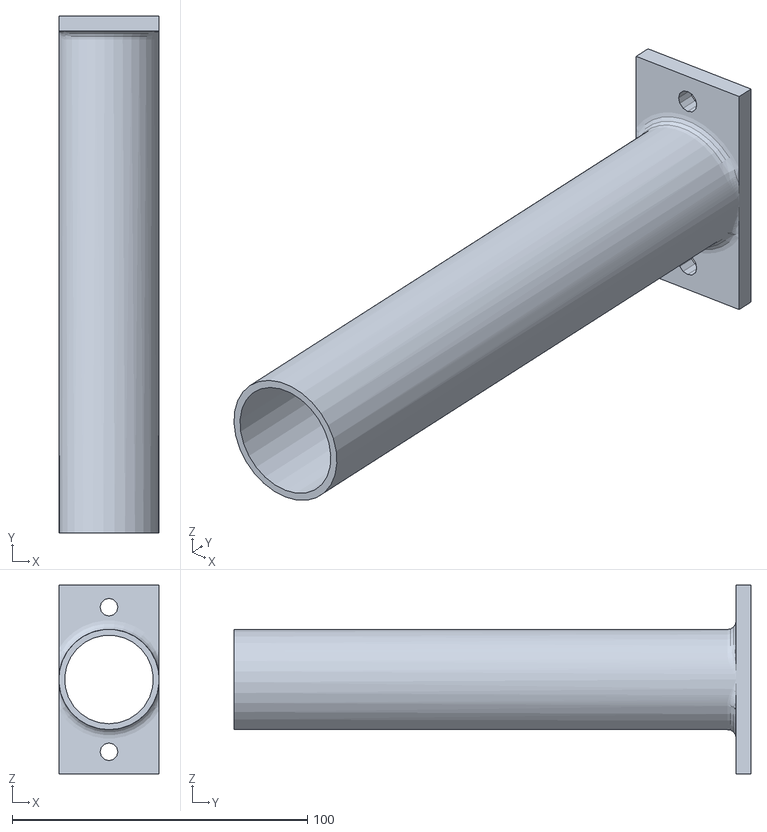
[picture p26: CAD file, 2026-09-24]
hardware/cad/sonar_mount_v2.stl
34.0 x 175.0 x 64.0

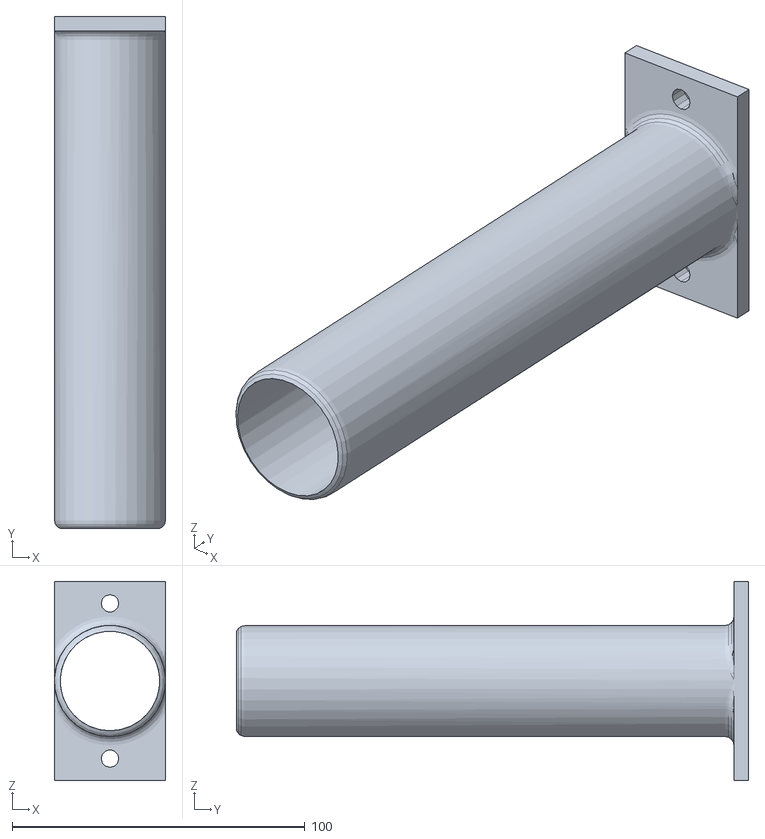
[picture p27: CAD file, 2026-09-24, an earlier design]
hardware/cad/sonar_mount_v1.stl
38.0 x 175.0 x 68.0

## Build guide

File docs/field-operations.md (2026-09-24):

# Field operations

## Before launch

1. Inspect the hull, cable penetrations, camera window, propellers, and battery restraint.
2. Clean both sides of the camera window and check for condensation.
3. Insert a formatted microSD card and confirm that the camera reports ready.
4. Power the vehicle with propellers clear of hands and loose material.
5. Wait for ESC arming and confirm neutral at 1500 us.
6. Wait for at least five satellites and acceptable HDOP.
7. Hold the boat over visible bottom and save several test frames.
8. Inspect full-resolution stone edges before committing to a mission.

## Mission capture

- Prefer 0.20-0.30 m/s on imaging lines.
- Keep the camera height as constant and as low as safe.
- Use dense forward overlap and 0.7-0.8 m lane spacing for the first area survey.
- Pause or mark images during turns.
- Use a second perpendicular pass when time and battery allow.
- Record water clarity, weather, waves, approximate depth, camera height, and any manual intervention.

## Recovery and data handling

1. Stop the motors before lifting the vehicle.
2. Power down before opening the electronics enclosure.
3. Copy the complete mission directory without renaming its images.
4. Calculate a SHA-256 checksum for the raw archive.
5. Keep raw files read-only and write all processed outputs to a separate directory.

## Minimum field note

```text
Mission ID:
Date and UTC interval:
Location:
Firmware versions:
Weather / waves:
Water clarity:
Estimated depth:
Camera height above bottom:
Route type and lane spacing:
Manual interventions:
Result and observed failures:
```

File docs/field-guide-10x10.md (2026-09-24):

# 10×10 Manual Orthophoto — полевой план

## Что эта версия решает

Эта прошивка специально убирает самую ненадёжную часть старой автономки: автоматические развороты и переходы между соседними полосами.

Рабочий цикл теперь такой:

```text
выбрать полосу
→ поставить робот на береговую метку
→ направить нос в воду
→ LOCK BOW
→ пройти одну прямую с плотной фотосъёмкой
→ автоматическая остановка у дальнего края
→ вручную вернуть робот
→ сдвинуть к следующей береговой метке
→ повторить
```

Внутри каждой полосы робот самостоятельно удерживает направление по MPU-6050, корректирует линию по GPS, делает фотографии и останавливается у дальнего края. Между полосами оператор полностью контролирует аппарат.

Это не гарантирует хороший ортофотоплан при нерезкой оптике или непрозрачной воде. Главный обязательный тест — резкий неподвижный кадр дна на реальной рабочей глубине.

---

## Что изменено в логике фотографий

Фотография запрашивается при одном из условий:

- аппарат прошёл примерно `0.20 м` вдоль полосы;
- прошло не менее `850 мс` и положение достаточно спокойное;
- прошло `1.25 с` — тогда снимок делается принудительно, чтобы не образовался разрыв покрытия.

Качественный момент определяется по крену, тангажу и угловой скорости MPU. Однако программа не ждёт идеальной стабильности бесконечно.

При ручном режиме фотографии выполняются только во время удержания `SLOW FORWARD + PHOTOS`. Повороты и движение назад кадры не создают.

Рекомендуемые настройки:

```text
Lane spacing: 0.70 m
Photo interval: 850 ms
```

Для квадрата 10×10 программа построит приблизительно:

```text
15 полос
фактический шаг около 0.66 м
рабочая длина полосы около 9.4 м
около 49 ожидаемых кадров на полосу
около 700–750 кадров на весь квадрат
```

---

## Подготовка камеры — обязательный этап

Перед разметкой маршрута:

1. Закрой старую фотомиссию.
2. Создай новую миссию.
3. Поставь робот неподвижно в воду на реальную рабочую глубину.
4. Подожди, пока поднятая муть осядет.
5. Сделай три `TEST PHOTO`.
6. Открой снимки в полном разрешении.

Начинать съёмку можно только когда на неподвижном кадре видны чёткие края камней, песка, травы или других деталей дна.

Если неподвижный кадр мягкий или мутный:

- протереть внешнее окно камеры;
- проверить конденсат внутри корпуса;
- проверить царапины и капли на окне;
- уменьшить расстояние камеры до дна;
- проверить фокус объектива на рабочем расстоянии именно в воде;
- подождать оседания мути;
- снизить тягу и не поднимать винтами осадок.

Из нерезких неподвижных кадров программно получить идеальный ортофотоплан невозможно.

---

## Разметка квадрата с берега

Используются только две точки:

```text
A ───────────────── D   берег
│                  │
│      10×10 м     │
│                  │
B ───────────────── C
```

- `A` — левый береговой угол;
- `D` — правый береговой угол;
- дальние углы рассчитываются автоматически;
- программа принудительно строит квадрат ровно 10×10 м.

Порядок:

1. Поставить робот в точку A.
2. Нажать `SAVE SHORE A` и ждать 6 секунд.
3. Поставить робот в точку D.
4. Нажать `SAVE SHORE D` и ждать 6 секунд.
5. Встать в A лицом к D.
6. Выбрать `WATER IS LEFT` или `WATER IS RIGHT`.
7. Установить `0.70 м` и `850 мс`.
8. Нажать `SAVE SETTINGS`.
9. Нажать `BUILD EXACT 10×10 GRID`.

После построения ожидается примерно:

```text
GRID: YES
LANES: 15
SPACING: около 0.66 m
```

---

## Как физически не пропустить полосу

Лучший способ — натянуть вдоль берега верёвку от A до D длиной 10 м и поставить на ней 15 заметных меток.

Первая метка располагается примерно в `0.35 м` от A. Следующие метки идут через фактическое значение `SHIFT NEXT`, которое показывает интерфейс, обычно около `0.66 м`.

Так боковой шаг определяется не шумным GPS, а физическими береговыми метками. GPS остаётся для удержания длинной линии и остановки возле дальнего края.

---

## Прохождение каждой полосы

Для полосы 1:

1. Выбрать `LANE 1`.
2. Поставить робот возле первой береговой метки.
3. Направить нос перпендикулярно берегу в воду.
4. Один раз после спуска нажать `SET WATER LEVEL ZERO`.
5. Нажать `LOCK BOW OUTWARD` и не трогать аппарат 2 секунды.
6. Нажать `ARM`.
7. Дождаться `LANE READY`.
8. Нажать `START ONE-WAY PHOTO LANE`.
9. Держать аварийную остановку открытой.

Робот должен:

```text
OUTBOUND
→ плотная фотосъёмка
→ остановка у дальнего края
→ FAR_HOLD
→ финальный снимок
→ COMPLETE
```

После завершения интерфейс показывает:

```text
LANE PHOTOS expected/saved/quality
```

- `GOOD` — перейти дальше;
- `CHECK` или событие `REPEAT` — пройти эту полосу ещё раз.

Далее:

1. Выключить `AUTO PHOTOS`, если он был включён.
2. Вручную развернуть и вернуть робот к берегу.
3. Нажать `NEXT LANE`.
4. Переставить аппарат на следующую береговую метку.
5. Снова направить нос в воду.
6. Повторно выполнить `LOCK BOW OUTWARD`.
7. Запустить следующую прямую.

Новый `LOCK BOW` выполняется перед каждой полосой. Это не позволяет ошибке гироскопа накапливаться через весь квадрат.

---

## Полностью ручной резервный режим

Если направляющая автоматика одной прямой начинает вести себя неправильно:

1. Нажать `EMERGENCY STOP`.
2. Нажать `AUTO PHOTOS ON`.
3. Управлять кнопками вручную.
4. На самой полосе удерживать только `SLOW FORWARD + PHOTOS`.
5. Для коррекции отпустить вперёд, коротко повернуть и снова продолжить прямую.

Фотографии не делаются во время `LEFT`, `RIGHT` и `REVERSE`, поэтому развороты не засоряют последовательность вращающимися кадрами.

В ручном режиме ориентироваться по береговым меткам и визуальной линии на противоположной стороне квадрата.

---

## Как повысить вероятность успешной сшивки

- Снимать в наиболее спокойный момент воды.
- Двигаться медленно и без резких рулений.
- Не менять высоту камеры над дном между полосами.
- Не менять экспозицию, направление камеры и корпус во время миссии.
- Не удалять отдельные кадры до создания резервной копии миссии.
- При разрешении правил положить высококонтрастные водостойкие метки в четырёх углах и центре квадрата. Они заметно помогают совмещению и масштабу.
- Повторить отдельную полосу, если вода временно помутнела или счётчик кадров низкий.

---

## После съёмки

1. Нажать `DISARM`.
2. Нажать `END PHOTO MISSION`.
3. Дождаться `MISSION: NONE`.
4. Выключить питание.
5. Извлечь SD только после выключения.
6. Скопировать целиком папку миссии:

```text
/missions/M00XX/
  images/
  telemetry.csv
  geo.txt
```

7. Сделать отдельную резервную копию.

Для обработки:

1. Отбросить явно нерезкие кадры, сохранив порядок файлов.
2. Применить одинаковую мягкую коррекцию цвета и контраста ко всем изображениям.
3. Сшивать сначала каждую полосу по последовательным соседним кадрам.
4. Затем соединять полосы между собой по боковому перекрытию.
5. Выровнять итоговую мозаику по известному квадрату 10×10 м или по контрастным угловым меткам.
6. Экспортировать итог как PNG/TIFF и отдельно сохранить таблицу использованных кадров.

Из-за преломления света в воде и отсутствия точной подводной калибровки это будет качественный ортомозаичный план для поиска объектов, но не геодезический продукт сантиметровой точности.

---

## Решение для соревнования

Основной режим:

```text
15 физических береговых меток
→ 15 независимых прямых
→ новый LOCK BOW перед каждой прямой
→ снимок примерно каждые 0.20 м
→ повтор полосы при низком счётчике
```

V6 с полностью автоматическими петлями можно тестировать отдельно после того, как безопасный набор фотографий уже записан.

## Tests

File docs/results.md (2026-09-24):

# Field results

## M0014: diagnostic mission

| Measure | Result |
| --- | ---: |
| Saved images | 362 |
| Resolution | 2048 x 1536 |
| Median image interval | about 1 s |
| Mean recorded speed | about 1.76 km/h |
| Median GPS displacement per frame | about 0.55 m |
| Median capture time | about 300 ms |
| Frames above the diagnostic detail threshold | about 8% |

M0014 was a useful failure. It proved that the camera and telemetry pipeline could run for hundreds of frames, but it did not provide enough stable image detail for a defensible mosaic. Sharpness remained poor even when speed and inertial stability were favorable, which pointed to focus, the housing window, turbidity, distance to the bottom, and illumination as the dominant problems.

## M0016: strongest field mission

| Measure | Result |
| --- | ---: |
| Saved images | 208 / 208 |
| Duration | 279 s |
| Outbound frames | 122 |
| Turning frames excluded | 9 |
| Return frames | 77 |
| Median speed | 0.945 km/h / 0.262 m/s |
| Median capture time | 445.5 ms |
| Stable-frame fraction | 38.0% |
| Median satellites | 6 |
| Median HDOP | 1.56 |
| Best-scoring frame | `IMG_000012.JPG` |

M0016 produced a continuous visual representation of the surveyed bottom corridor. Rocky sections retained recognizable texture. The central sandy section remained less reliable because it had weaker texture, greater haze, and changing sunlight patterns.

The result supports three conclusions:

1. The two-controller platform can capture and preserve a complete synchronized field sequence.
2. Redundant outbound and return observations improve continuity by allowing a clearer frame to replace a weaker one.
3. Better navigation alone is not enough; optical calibration and controlled camera geometry are required for metric mapping.

## What was demonstrated

- Reliable local image storage with synchronized GNSS and IMU telemetry.
- A complete 208-frame field run without a missing expected image.
- A connected feature-aligned reconstruction of one underwater transect.
- Practical identification of the optical and geometric limits of the low-cost setup.

## What was not demonstrated

- A validated autonomous 10 x 10 m coverage mission.
- A survey-grade orthophoto or bathymetric map.
- Reliable material classification from sonar or imagery.
- Centimeter-level positioning.

The raw evidence and derived files for both missions are available under [`../data/`](../data/).

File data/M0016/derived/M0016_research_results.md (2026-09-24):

# M0016 Experimental Strip Orthomosaic — Research Result

## Dataset and acquisition

Mission M0016 contains **208 geotagged images** from one manually controlled outbound-and-return transect. The sequence was divided into **122 outbound frames**, **9 turning frames**, and **77 return frames**. Turning frames were excluded because camera rotation and acceleration reduce geometric consistency. The total recording duration was approximately **279 s**. Median speed was **0.94 km/h**, median capture time was **446 ms**, and **38.0%** of frames were classified as stable by the onboard inertial filter.

## Processing method

GPS coordinates were converted to local metric coordinates and smoothed into a monotonic 0–10 m transect model. Return images were rotated by 180° so both passes shared the same ground orientation. Each image was assigned a quality score using edge sharpness, contrast, tonal range, and inertial stability. At 0.2 m stations, the higher-quality observation from the outbound or return pass was selected. Selected image strips were white-balanced, contrast-enhanced, mildly sharpened, and fused into a pushbroom-style corridor mosaic.

## Result

The output demonstrates a continuous representation of the lake bottom along the surveyed line. Rocky regions are visibly distinguishable and preserve useful texture. The central sandy region is less reliable because turbidity, low texture, and moving sunlight patterns reduce repeatable visual features. Combining two passes improves continuity because the processing pipeline can select the clearer observation at each station.

This result should be described as an **experimental strip orthomosaic or corridor mosaic**, not as a complete 10 × 10 m orthophotoplan. Only one line was surveyed, underwater camera calibration was unavailable, camera height above the bottom was not measured, and consumer GPS cannot provide survey-grade placement. A complete area product requires the same acquisition procedure over parallel lanes with lateral overlap.

## Quantitative results

- Total images: **208**
- Frames used as source pools: **122 outbound + 77 return**
- Frames excluded during turning: **9**
- Median image capture time: **446 ms**
- Median reported speed: **0.94 km/h**
- Stable-frame fraction: **38.0%**
- Median satellites: **6**
- Median HDOP: **1.56**
- Best quality frame: **IMG_000012.JPG**

## Research interpretation

The trial confirms that a low-cost camera can produce usable bottom imagery when stones provide texture and the water is locally clear. Two-pass acquisition is beneficial because it creates redundant observations and allows low-quality frames to be replaced. The primary remaining limitations are underwater focus, turbidity, illumination changes, and the absence of calibrated scale. These findings directly support the next design iteration: slower straight-line motion, dense parallel lanes, fixed camera height, calibrated optics, and deliberate exclusion of turns from the imaging sequence.

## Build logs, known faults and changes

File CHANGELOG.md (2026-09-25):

# Changelog

All notable repository releases are documented here.

## 1.0.1 - 2026-09-25

- Added original high-resolution field photographs of the completed vehicle.
- Added the recovered bill of materials and explicit record of missing hardware specifications.
- Added firmware compilation CI for the main controller, field mode, and camera controller.
- Added GitHub issue forms, pull-request guidance, ownership, security policy, and code of conduct.
- Added a machine-readable Apache-2.0 software license while retaining CC BY 4.0 for original data and documentation.
- Expanded the README with mission goals, headline results, archive completeness, and a complete quick start.

## 1.0.0 - 2026-07-18

- Preserved final main ESP32 and ESP32-S3 camera firmware.
- Preserved recovered M0014 and M0016 raw mission archives through Git LFS.
- Added synchronized telemetry, OpenDroneMap-compatible geolocation files, derived diagnostics, and reconstruction results.
- Added the final DeepSeeker paper, CAD files, planning tools, development history, reproducible telemetry analysis, and tests.

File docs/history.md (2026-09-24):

# Development history

The version archive documents how the vehicle moved from basic manual control to synchronized imaging and experimental autonomous coverage.

| Version | Main change |
| --- | --- |
| v4.1 | Wi-Fi water-test control |
| v4.2 | Smoother motion commands |
| v4.3 | Reliability changes after water tests |
| v4.4 | Gentler turning behavior |
| v4.5 | MPU-6050 yaw-rate damping and bow control experiments |
| v5.0 | Lawn-mower survey generation |
| v5.1 | Four recorded corners matched to a survey route |
| v5.1.1 | Compile corrections |
| v5.1.2 | Camera status handling |
| v5.1.3 | Connector stop behavior |
| v6.0 | Interlaced teardrop route and final integrated controller snapshot |

The camera line likewise progressed from basic UART capture to geotagged mission folders and microSD retry handling. The final preserved camera snapshot is `v2.2_sd_retry`.

These files are historical field artifacts. They are intentionally not normalized into one polished codebase because that would erase the exact versions used during testing.

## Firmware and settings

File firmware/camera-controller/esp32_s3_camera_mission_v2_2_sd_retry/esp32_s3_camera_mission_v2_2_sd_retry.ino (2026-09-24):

#include <Arduino.h>
#include <WiFi.h>
#include <WebServer.h>

#include "esp_camera.h"
#include "FS.h"
#include "SD_MMC.h"

// ============================================================
// Wi-Fi
// ============================================================

const char* WIFI_NAME = "CATAMARAN-CAM";
const char* WIFI_PASSWORD = "12345678";

WebServer server(80);

// ============================================================
// UART-связь с основной ESP32
// Основная ESP32 GPIO14 TX -> S3 GPIO1 RX
// Основная ESP32 GPIO13 RX <- S3 GPIO2 TX
// ============================================================

constexpr uint32_t CONTROLLER_UART_BAUD = 115200;
constexpr int CONTROLLER_UART_RX_PIN = 1;
constexpr int CONTROLLER_UART_TX_PIN = 2;

HardwareSerial ControllerSerial(1);
String controllerInputLine;

// ============================================================
// Настройки изображения
// ============================================================

// 0 или 1
#define CAMERA_VERTICAL_FLIP      0
#define CAMERA_HORIZONTAL_MIRROR  0

// Пока тестируем в 1024x768.
// После успешных 100/100 можно заменить на FRAMESIZE_QXGA.
const framesize_t CAMERA_FRAME_SIZE = FRAMESIZE_QXGA;

// Чем меньше число, тем выше качество JPEG.
// Рабочий диапазон обычно 8–20.
const int CAMERA_JPEG_QUALITY = 10;

// ============================================================
// GOOUUU ESP32-S3-CAM V1.5 + OV3660
// Рабочая распиновка камеры
// ============================================================

#define CAM_PWDN   -1
#define CAM_RESET  -1

#define CAM_XCLK   15
#define CAM_SIOD    4
#define CAM_SIOC    5

#define CAM_D0     11
#define CAM_D1      9
#define CAM_D2      8
#define CAM_D3     10
#define CAM_D4     12
#define CAM_D5     18
#define CAM_D6     17
#define CAM_D7     16

#define CAM_VSYNC   6
#define CAM_HREF    7
#define CAM_PCLK   13

// ============================================================
// Встроенная microSD, SD_MMC 1-bit
// ============================================================

#define SD_CLK 39
#define SD_CMD 38
#define SD_D0  40

// ============================================================
// Глобальное состояние
// ============================================================

bool cameraReady = false;
bool sdReady = false;

constexpr uint32_t SD_RETRY_INTERVAL_MS = 3000;
uint32_t lastSdRetryMs = 0;

uint32_t photoNumber = 1;

// ============================================================
// Mission storage
// ============================================================

const char* MISSIONS_ROOT = "/missions";
const char* MISSION_COUNTER_FILE = "/mission_counter.txt";
const char* MISSION_STATE_FILE = "/mission_state.txt";

bool missionActive = false;
uint32_t currentMissionNumber = 0;
uint32_t missionPhotoNumber = 1;
String currentMissionPath = "";


// ============================================================
// Состояние стресс-теста
// ============================================================

struct StressTestState {
  bool active = false;

  uint32_t targetPhotos = 100;
  uint32_t attempted = 0;
  uint32_t successful = 0;
  uint32_t failed = 0;

  uint32_t intervalMs = 1000;
  uint32_t lastCaptureAt = 0;
  uint32_t startedAt = 0;

  String lastFile = "";
  String lastError = "";
};

StressTestState stressTest;

// ============================================================
// Инициализация камеры
// ============================================================

bool initCamera() {
  camera_config_t config = {};

  config.ledc_channel = LEDC_CHANNEL_0;
  config.ledc_timer = LEDC_TIMER_0;

  config.pin_d0 = CAM_D0;
  config.pin_d1 = CAM_D1;
  config.pin_d2 = CAM_D2;
  config.pin_d3 = CAM_D3;
  config.pin_d4 = CAM_D4;
  config.pin_d5 = CAM_D5;
  config.pin_d6 = CAM_D6;
  config.pin_d7 = CAM_D7;

  config.pin_xclk = CAM_XCLK;
  config.pin_pclk = CAM_PCLK;
  config.pin_vsync = CAM_VSYNC;
  config.pin_href = CAM_HREF;

  config.pin_sccb_sda = CAM_SIOD;
  config.pin_sccb_scl = CAM_SIOC;

  config.pin_pwdn = CAM_PWDN;
  config.pin_reset = CAM_RESET;

  config.xclk_freq_hz = 20000000;
  config.pixel_format = PIXFORMAT_JPEG;

  if (psramFound()) {
    Serial.println("PSRAM found");

    config.frame_size = CAMERA_FRAME_SIZE;
    config.jpeg_quality = CAMERA_JPEG_QUALITY;
    config.fb_count = 2;
    config.fb_location = CAMERA_FB_IN_PSRAM;
    config.grab_mode = CAMERA_GRAB_LATEST;
  } else {
    Serial.println("WARNING: PSRAM not found");
    Serial.println("Using safe low-resolution mode");

    config.frame_size = FRAMESIZE_VGA;
    config.jpeg_quality = 12;
    config.fb_count = 1;
    config.fb_location = CAMERA_FB_IN_DRAM;
    config.grab_mode = CAMERA_GRAB_WHEN_EMPTY;
  }

  esp_err_t error = esp_camera_init(&config);

  if (error != ESP_OK) {
    Serial.printf(
      "Camera initialization failed: 0x%X\n",
      error
    );

    return false;
  }

  sensor_t* sensor = esp_camera_sensor_get();

  if (sensor == nullptr) {
    Serial.println("Camera sensor pointer is null");
    return false;
  }

  sensor->set_vflip(
    sensor,
    CAMERA_VERTICAL_FLIP
  );

  sensor->set_hmirror(
    sensor,
    CAMERA_HORIZONTAL_MIRROR
  );

  sensor->set_brightness(sensor, 0);
  sensor->set_saturation(sensor, 0);
  sensor->set_contrast(sensor, 0);

  Serial.printf(
    "Camera sensor PID: 0x%04X\n",
    sensor->id.PID
  );

  // Несколько первых кадров отбрасываем,
  // чтобы настроились экспозиция и баланс белого.
  for (int i = 0; i < 4; i++) {
    camera_fb_t* frame = esp_camera_fb_get();

    if (frame != nullptr) {
      esp_camera_fb_return(frame);
    }

    delay(200);
  }

  Serial.println("Camera initialized successfully");
  return true;
}

// ============================================================
// Инициализация SD
// ============================================================

bool initSD() {
  Serial.println("Initializing SD card...");

  if (!SD_MMC.setPins(SD_CLK, SD_CMD, SD_D0)) {
    Serial.println("SD_MMC.setPins failed");
    return false;
  }

  // true = однобитный режим
  if (!SD_MMC.begin("/sdcard", true)) {
    Serial.println("SD card mount failed");
    return false;
  }

  if (SD_MMC.cardType() == CARD_NONE) {
    Serial.println("No SD card detected");
    return false;
  }

  uint64_t cardSizeMB =
    SD_MMC.cardSize() / (1024ULL * 1024ULL);

  uint64_t totalMB =
    SD_MMC.totalBytes() / (1024ULL * 1024ULL);

  uint64_t usedMB =
    SD_MMC.usedBytes() / (1024ULL * 1024ULL);

  Serial.printf("SD card size: %llu MB\n", cardSizeMB);
  Serial.printf("SD total: %llu MB\n", totalMB);
  Serial.printf("SD used: %llu MB\n", usedMB);

  if (!SD_MMC.exists("/photos")) {
    if (!SD_MMC.mkdir("/photos")) {
      Serial.println("Failed to create /photos");
      return false;
    }
  }

  // Ищем следующий свободный номер.
  while (photoNumber < 1000000) {
    char path[48];

    snprintf(
      path,
      sizeof(path),
      "/photos/IMG_%06lu.JPG",
      static_cast<unsigned long>(photoNumber)
    );

    if (!SD_MMC.exists(path)) {
      break;
    }

    photoNumber++;
  }

  Serial.printf(
    "Next photo number: %lu\n",
    static_cast<unsigned long>(photoNumber)
  );

  Serial.println("SD initialized successfully");
  return true;
}

bool retrySdMountBasic() {
  if (sdReady) {
    return true;
  }

  Serial.println("Retrying SD card mount...");
  SD_MMC.end();
  delay(80);

  sdReady = initSD();

  if (sdReady) {
    Serial.println("SD card is now READY");
  }

  return sdReady;
}


// ============================================================
// Сохранение одного снимка
// ============================================================

bool savePhoto(
  String& savedPath,
  size_t& savedBytes,
  uint32_t& captureTimeMs,
  String& errorMessage
) {
  savedPath = "";
  savedBytes = 0;
  captureTimeMs = 0;
  errorMessage = "";

  if (!cameraReady) {
    errorMessage = "Camera is not ready";
    return false;
  }

  if (!sdReady) {
    errorMessage = "SD card is not ready";
    return false;
  }

  uint32_t startedAt = millis();

  camera_fb_t* frame = esp_camera_fb_get();

  if (frame == nullptr) {
    errorMessage = "Camera capture failed";
    return false;
  }

  if (frame->format != PIXFORMAT_JPEG) {
    errorMessage = "Frame is not JPEG";
    esp_camera_fb_return(frame);
    return false;
  }

  const size_t frameLength = frame->len;
  const uint16_t frameWidth = frame->width;
  const uint16_t frameHeight = frame->height;

  char path[48];

  snprintf(
    path,
    sizeof(path),
    "/photos/IMG_%06lu.JPG",
    static_cast<unsigned long>(photoNumber)
  );

  File file = SD_MMC.open(path, FILE_WRITE);

  if (!file) {
    errorMessage = "Could not create file";
    esp_camera_fb_return(frame);
    return false;
  }

  size_t written = file.write(
    frame->buf,
    frame->len
  );

  file.flush();
  file.close();

  esp_camera_fb_return(frame);

  captureTimeMs = millis() - startedAt;

  if (written != frameLength) {
    errorMessage = "Incomplete SD write";

    Serial.printf(
      "Write error: expected %u, written %u\n",
      static_cast<unsigned int>(frameLength),
      static_cast<unsigned int>(written)
    );

    return false;
  }

  savedPath = path;
  savedBytes = written;

  Serial.printf(
    "Saved: %s | %ux%u | %u bytes | %lu ms\n",
    path,
    frameWidth,
    frameHeight,
    static_cast<unsigned int>(written),
    static_cast<unsigned long>(captureTimeMs)
  );

  photoNumber++;

  return true;
}

// ============================================================
// Mission helpers
// ============================================================

String makeMissionPath(uint32_t missionNumber) {
  char path[32];
  snprintf(
    path,
    sizeof(path),
    "/missions/M%04lu",
    static_cast<unsigned long>(missionNumber)
  );
  return String(path);
}

bool ensureDirectory(const String& path) {
  if (SD_MMC.exists(path)) {
    return true;
  }

  return SD_MMC.mkdir(path);
}

uint32_t readMissionCounter() {
  if (!SD_MMC.exists(MISSION_COUNTER_FILE)) {
    return 0;
  }

  File file = SD_MMC.open(MISSION_COUNTER_FILE, FILE_READ);
  if (!file) {
    return 0;
  }

  uint32_t value = file.parseInt();
  file.close();
  return value;
}

bool writeMissionCounter(uint32_t value) {
  File file = SD_MMC.open(MISSION_COUNTER_FILE, FILE_WRITE);
  if (!file) {
    return false;
  }

  file.print(value);
  file.print("\n");
  file.flush();
  file.close();
  return true;
}

bool writeMissionState() {
  File file = SD_MMC.open(MISSION_STATE_FILE, FILE_WRITE);
  if (!file) {
    return false;
  }

  file.print(currentMissionNumber);
  file.print(",");
  file.print(missionPhotoNumber);
  file.print("\n");
  file.flush();
  file.close();
  return true;
}

void clearMissionState() {
  if (SD_MMC.exists(MISSION_STATE_FILE)) {
    SD_MMC.remove(MISSION_STATE_FILE);
  }
}

bool createGeoFile(const String& missionPath) {
  String geoPath = missionPath + "/geo.txt";

  if (SD_MMC.exists(geoPath)) {
    return true;
  }

  File file = SD_MMC.open(geoPath, FILE_WRITE);
  if (!file) {
    return false;
  }

  // OpenDroneMap image geolocation file. For EPSG:4326:
  // X = longitude, Y = latitude.
  file.println("EPSG:4326");
  file.flush();
  file.close();
  return true;
}

bool createTelemetryFile(const String& missionPath) {
  String csvPath = missionPath + "/telemetry.csv";

  if (SD_MMC.exists(csvPath)) {
    return true;
  }

  File file = SD_MMC.open(csvPath, FILE_WRITE);
  if (!file) {
    return false;
  }

  file.println(
    "image,utc,latitude,longitude,altitude_m,satellites,hdop,"
    "speed_kmph,course_deg,roll_deg,pitch_deg,gyro_x_dps,"
    "gyro_y_dps,gyro_z_dps,total_acc_g,stable,level,jpeg_bytes,capture_ms"
  );

  file.flush();
  file.close();
  return true;
}

bool startNewMission(String& errorMessage) {
  errorMessage = "";

  if (!sdReady && !retrySdMountBasic()) {
    errorMessage = "SD_NOT_READY";
    return false;
  }

  if (missionActive) {
    errorMessage = "MISSION_ALREADY_ACTIVE";
    return false;
  }

  if (!ensureDirectory(MISSIONS_ROOT)) {
    errorMessage = "MISSIONS_ROOT_CREATE_FAILED";
    return false;
  }

  uint32_t candidate = readMissionCounter() + 1;

  while (candidate < 10000) {
    String candidatePath = makeMissionPath(candidate);
    if (!SD_MMC.exists(candidatePath)) {
      break;
    }
    candidate++;
  }

  if (candidate >= 10000) {
    errorMessage = "MISSION_NUMBER_LIMIT";
    return false;
  }

  currentMissionNumber = candidate;
  currentMissionPath = makeMissionPath(currentMissionNumber);
  missionPhotoNumber = 1;

  if (!ensureDirectory(currentMissionPath)) {
    errorMessage = "MISSION_DIR_CREATE_FAILED";
    return false;
  }

  String imagesPath = currentMissionPath + "/images";
  if (!ensureDirectory(imagesPath)) {
    errorMessage = "IMAGES_DIR_CREATE_FAILED";
    return false;
  }

  if (!createTelemetryFile(currentMissionPath)) {
    errorMessage = "TELEMETRY_CREATE_FAILED";
    return false;
  }

  if (!createGeoFile(currentMissionPath)) {
    errorMessage = "GEO_CREATE_FAILED";
    return false;
  }

  missionActive = true;

  if (!writeMissionCounter(currentMissionNumber)) {
    missionActive = false;
    errorMessage = "COUNTER_WRITE_FAILED";
    return false;
  }

  if (!writeMissionState()) {
    missionActive = false;
    errorMessage = "STATE_WRITE_FAILED";
    return false;
  }

  return true;
}

bool resumeMissionFromState() {
  missionActive = false;
  currentMissionNumber = 0;
  missionPhotoNumber = 1;
  currentMissionPath = "";

  if (!sdReady || !SD_MMC.exists(MISSION_STATE_FILE)) {
    return false;
  }

  File file = SD_MMC.open(MISSION_STATE_FILE, FILE_READ);
  if (!file) {
    return false;
  }

  String line = file.readStringUntil('\n');
  file.close();
  line.trim();

  int comma = line.indexOf(',');
  if (comma < 1) {
    clearMissionState();
    return false;
  }

  uint32_t missionNumber = line.substring(0, comma).toInt();
  uint32_t nextPhoto = line.substring(comma + 1).toInt();

  if (missionNumber == 0 || nextPhoto == 0) {
    clearMissionState();
    return false;
  }

  String missionPath = makeMissionPath(missionNumber);
  String imagesPath = missionPath + "/images";
  String csvPath = missionPath + "/telemetry.csv";

  if (
    !SD_MMC.exists(missionPath) ||
    !SD_MMC.exists(imagesPath) ||
    !SD_MMC.exists(csvPath)
  ) {
    clearMissionState();
    return false;
  }

  if (!createGeoFile(missionPath)) {
    clearMissionState();
    return false;
  }

  currentMissionNumber = missionNumber;
  missionPhotoNumber = nextPhoto;
  currentMissionPath = missionPath;
  missionActive = true;
  return true;
}

bool endMission(String& errorMessage) {
  errorMessage = "";

  if (!missionActive) {
    errorMessage = "NO_ACTIVE_MISSION";
    return false;
  }

  clearMissionState();
  missionActive = false;
  currentMissionNumber = 0;
  missionPhotoNumber = 1;
  currentMissionPath = "";
  return true;
}

bool appendMissionTelemetry(
  const String& imagePath,
  const String& telemetryPayload,
  size_t jpegBytes,
  uint32_t captureTimeMs
) {
  if (!missionActive) {
    return false;
  }

  String csvPath = currentMissionPath + "/telemetry.csv";
  File file = SD_MMC.open(csvPath, FILE_APPEND);

  if (!file) {
    return false;
  }

  int slash = imagePath.lastIndexOf('/');
  String imageName =
    slash >= 0 ? imagePath.substring(slash + 1) : imagePath;

  file.print(imageName);
  file.print(",");
  file.print(telemetryPayload);
  file.print(",");
  file.print(static_cast<unsigned int>(jpegBytes));
  file.print(",");
  file.println(captureTimeMs);

  file.flush();
  file.close();
  return true;
}

String getCsvField(const String& text, int fieldIndex) {
  int start = 0;
  int current = 0;

  while (true) {
    int comma = text.indexOf(',', start);

    if (current == fieldIndex) {
      if (comma < 0) {
        return text.substring(start);
      }
      return text.substring(start, comma);
    }

    if (comma < 0) {
      return "";
    }

    start = comma + 1;
    current++;
  }
}

bool appendMissionGeo(
  const String& imagePath,
  const String& telemetryPayload
) {
  if (!missionActive) {
    return false;
  }

  // telemetryPayload fields sent by Main ESP32:
  // 0 utc, 1 latitude, 2 longitude, 3 altitude, ...
  String latitude = getCsvField(telemetryPayload, 1);
  String longitude = getCsvField(telemetryPayload, 2);
  String altitude = getCsvField(telemetryPayload, 3);

  latitude.trim();
  longitude.trim();
  altitude.trim();

  if (
    latitude.length() == 0 || longitude.length() == 0 ||
    latitude == "NA" || longitude == "NA"
  ) {
    return false;
  }

  if (altitude.length() == 0 || altitude == "NA") {
    altitude = "0";
  }

  int slash = imagePath.lastIndexOf('/');
  String imageName =
    slash >= 0 ? imagePath.substring(slash + 1) : imagePath;

  String geoPath = currentMissionPath + "/geo.txt";
  File file = SD_MMC.open(geoPath, FILE_APPEND);
  if (!file) {
    return false;
  }

  // ODM format for EPSG:4326: image_name longitude latitude altitude
  file.print(imageName);
  file.print(" ");
  file.print(longitude);
  file.print(" ");
  file.print(latitude);
  file.print(" ");
  file.println(altitude);
  file.flush();
  file.close();
  return true;
}

bool saveMissionPhoto(
  String& savedPath,
  size_t& savedBytes,
  uint32_t& captureTimeMs,
  String& errorMessage
) {
  savedPath = "";
  savedBytes = 0;
  captureTimeMs = 0;
  errorMessage = "";

  if (!cameraReady) {
    errorMessage = "CAMERA_NOT_READY";
    return false;
  }

  if (!sdReady) {
    errorMessage = "SD_NOT_READY";
    return false;
  }

  if (!missionActive) {
    errorMessage = "NO_ACTIVE_MISSION";
    return false;
  }

  uint32_t startedAt = millis();
  camera_fb_t* frame = esp_camera_fb_get();

  if (frame == nullptr) {
    errorMessage = "CAMERA_CAPTURE_FAILED";
    return false;
  }

  if (frame->format != PIXFORMAT_JPEG) {
    esp_camera_fb_return(frame);
    errorMessage = "FRAME_NOT_JPEG";
    return false;
  }

  char path[128];
  snprintf(
    path,
    sizeof(path),
    "%s/images/IMG_%06lu.JPG",
    currentMissionPath.c_str(),
    static_cast<unsigned long>(missionPhotoNumber)
  );

  File file = SD_MMC.open(path, FILE_WRITE);
  if (!file) {
    esp_camera_fb_return(frame);
    errorMessage = "IMAGE_FILE_CREATE_FAILED";
    return false;
  }

  const size_t frameLength = frame->len;
  size_t written = file.write(frame->buf, frame->len);
  file.flush();
  file.close();
  esp_camera_fb_return(frame);

  captureTimeMs = millis() - startedAt;

  if (written != frameLength) {
    errorMessage = "INCOMPLETE_SD_WRITE";
    return false;
  }

  savedPath = String(path);
  savedBytes = written;
  missionPhotoNumber++;

  if (!writeMissionState()) {
    errorMessage = "STATE_UPDATE_FAILED";
    return false;
  }

  Serial.printf(
    "Mission photo saved: %s | %u bytes | %lu ms\n",
    path,
    static_cast<unsigned int>(written),
    static_cast<unsigned long>(captureTimeMs)
  );

  return true;
}

// ============================================================
// Запуск стресс-теста
// ============================================================

bool startStressTest(
  uint32_t photoCount,
  uint32_t intervalMs
) {
  if (stressTest.active) {
    return false;
  }

  if (!cameraReady || !sdReady) {
    return false;
  }

  stressTest.active = true;

  stressTest.targetPhotos = photoCount;
  stressTest.attempted = 0;
  stressTest.successful = 0;
  stressTest.failed = 0;

  stressTest.intervalMs = intervalMs;
  stressTest.lastCaptureAt = 0;
  stressTest.startedAt = millis();

  stressTest.lastFile = "";
  stressTest.lastError = "";

  Serial.println();
  Serial.println("==================================");
  Serial.println("STRESS TEST STARTED");
  Serial.printf(
    "Target photos: %lu\n",
    static_cast<unsigned long>(photoCount)
  );
  Serial.printf(
    "Interval: %lu ms\n",
    static_cast<unsigned long>(intervalMs)
  );
  Serial.println("==================================");

  return true;
}

// ============================================================
// Остановка стресс-теста
// ============================================================

void stopStressTest(const String& reason) {
  if (!stressTest.active) {
    return;
  }

  stressTest.active = false;

  uint32_t duration =
    millis() - stressTest.startedAt;

  Serial.println();
  Serial.println("==================================");
  Serial.println("STRESS TEST FINISHED");
  Serial.print("Reason: ");
  Serial.println(reason);

  Serial.printf(
    "Attempted: %lu\n",
    static_cast<unsigned long>(stressTest.attempted)
  );

  Serial.printf(
    "Successful: %lu\n",
    static_cast<unsigned long>(stressTest.successful)
  );

  Serial.printf(
    "Failed: %lu\n",
    static_cast<unsigned long>(stressTest.failed)
  );

  Serial.printf(
    "Duration: %lu ms\n",
    static_cast<unsigned long>(duration)
  );

  Serial.println("==================================");
}

// ============================================================
// Неблокирующее выполнение стресс-теста
// ============================================================
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
void loop() {
  updateControllerUart();
  server.handleClient();
  updateStressTest();

  if (!sdReady && millis() - lastSdRetryMs >= SD_RETRY_INTERVAL_MS) {
    lastSdRetryMs = millis();

    if (retrySdMountBasic()) {
      if (!missionActive && resumeMissionFromState()) {
        Serial.print("Mission resumed after SD retry: ");
        Serial.println(currentMissionPath);
      }

      sendControllerStatus();
    }
  }

  delay(2);
}

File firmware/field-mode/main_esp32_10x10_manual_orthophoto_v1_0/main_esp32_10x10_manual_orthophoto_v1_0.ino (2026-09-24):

#include <Arduino.h>
#include <Wire.h>
#include <math.h>
#include <TinyGPSPlus.h>
#include <ESP32Servo.h>
#include <WiFi.h>
#include <WebServer.h>
#include <Preferences.h>

// Geometry types must be declared before Arduino generates function prototypes.
// Keeping them at the top avoids the Arduino preprocessor error
// "LocalPoint/GeoPoint does not name a type".
struct GeoPoint {
  double lat;
  double lon;
};

struct LocalPoint {
  float x;  // east, metres
  float y;  // north, metres
};

// ============================================================
// ОСНОВНАЯ ESP32
//
// MPU-6050:
//   SDA -> GPIO21
//   SCL -> GPIO22
//
// UART к ESP32-S3-CAM:
//   GPIO14 TX -> S3 GPIO1 RX
//   GPIO13 RX <- S3 GPIO2 TX
//   GND        -> GND
//
// GPS GY-NEO6MV2:
//   GPS TX -> ESP32 GPIO16 RX
//   GPS RX -> ESP32 GPIO17 TX (необязательно для чтения)
//   GND    -> GND
// ============================================================

// ============================================================
// ESC / differential thrust
// Tested physical orientation:
//   left ESC signal  -> GPIO25
//   right ESC signal -> GPIO2
//   equal forward PWM drives straight.
// ============================================================

constexpr int ESC_LEFT_PIN = 25;
constexpr int ESC_RIGHT_PIN = 2;
constexpr int ESC_NEUTRAL_US = 1500;

// Conservative automatic range. Lower pulse = more forward thrust
// on this specific catamaran/ESC setup.
// ESC calibration confirmed on this boat:
//   1500 us = neutral/stop
//   lower pulse = more forward thrust
//   1000 us = maximum forward command (NOT used in first water tests)
constexpr int ESC_MAX_FORWARD_US = 1000;

// Conservative first-water-test values.
// These deliberately stay far away from 1000 us.
constexpr int AUTO_FAST_US = 1300;
constexpr int AUTO_CRUISE_US = 1350;
constexpr int AUTO_SLOW_US = 1420;
constexpr int AUTO_FORWARD_LIMIT_US = 1180;
constexpr int AUTO_NEUTRAL_LIMIT_US = 1470;

constexpr uint32_t ESC_ARM_DELAY_MS = 12000;
constexpr uint32_t MOTOR_TEST_DURATION_MS = 1200;
constexpr uint32_t MANUAL_COMMAND_TIMEOUT_MS = 700;

Servo escLeft;
Servo escRight;

bool motorsArmed = false;
int currentLeftUs = ESC_NEUTRAL_US;
int currentRightUs = ESC_NEUTRAL_US;
uint32_t bootStartedMs = 0;
uint32_t motorTestStopAtMs = 0;
bool manualDriveActive = false;
uint32_t lastManualCommandMs = 0;

// Positive trim makes the right motor weaker in forward motion by moving
// its pulse closer to the 1500 us neutral point.
// Field observation: the right motor is stronger, so start with +20 us.
constexpr int RIGHT_FORWARD_TRIM_DEFAULT_US = 20;
constexpr int RIGHT_FORWARD_TRIM_MIN_US = -80;
constexpr int RIGHT_FORWARD_TRIM_MAX_US = 80;
int rightForwardTrimUs = RIGHT_FORWARD_TRIM_DEFAULT_US;

// Human-readable event visible on the web page.
String lastSystemEvent = "BOOT";

// Main-controller Wi-Fi is only a setup/safety interface.
// Autonomous navigation runs locally and does not require the phone to stay connected.
const char* CONTROL_AP_NAME = "CATAMARAN-CONTROL";
const char* CONTROL_AP_PASS = "12345678";
WebServer controlServer(80);
Preferences preferences;

enum class SurveyPointSlot : uint8_t { NONE, A, B, C, D };


// Explicit prototypes for functions that use custom geometry types.
// Arduino otherwise may auto-generate these prototypes above the type definitions.
LocalPoint geoToLocal(const GeoPoint& origin, const GeoPoint& point);
GeoPoint localToGeo(const GeoPoint& origin, const LocalPoint& point);
float localLength(const LocalPoint& point);
float distanceToGeo(const GeoPoint& point);
void setActiveTarget(const GeoPoint& point);
float cross2D(const LocalPoint& a, const LocalPoint& b, const LocalPoint& c);
float localDistance(const LocalPoint& a, const LocalPoint& b);
LocalPoint interpolateLocal(const LocalPoint& a, const LocalPoint& b, float t);
float polygonArea4(const LocalPoint& a, const LocalPoint& b, const LocalPoint& c, const LocalPoint& d);
bool orderedConvexQuadrilateral(
  const LocalPoint& a,
  const LocalPoint& b,
  const LocalPoint& c,
  const LocalPoint& d
);
bool chooseSurveyLockTarget(GeoPoint& target, bool& approachStart);
bool requestSurveyCapture();
bool surveyPhotoQualityOkay();
void configureActiveLegStopTimes(uint32_t nowMs);
void beginStraightLeg(const GeoPoint& start, const GeoPoint& finish, bool outbound);
void beginFarTurn();
SurveyPointSlot surveyPointAveragingSlot = SurveyPointSlot::NONE;
uint32_t surveyPointAverageStartedMs = 0;
uint32_t surveyPointAverageLastSampleMs = 0;
double surveyPointAverageLatSum = 0.0;
double surveyPointAverageLonSum = 0.0;
uint32_t surveyPointAverageSamples = 0;
constexpr uint32_t SURVEY_POINT_AVERAGE_DURATION_MS = 6000;
constexpr uint32_t SURVEY_POINT_AVERAGE_SAMPLE_INTERVAL_MS = 200;

// ============================================================
// MPU-6050
// ============================================================

constexpr uint8_t MPU_ADDRESS = 0x68;
constexpr int I2C_SDA_PIN = 21;
constexpr int I2C_SCL_PIN = 22;

// ============================================================
// UART камеры
// Используем UART1, чтобы UART2 позже оставить GPS на GPIO16/17.
// ============================================================

constexpr uint32_t CAMERA_UART_BAUD = 115200;
constexpr int CAMERA_UART_RX_PIN = 13;
constexpr int CAMERA_UART_TX_PIN = 14;

HardwareSerial CameraSerial(1);
String cameraInputLine;

bool cameraOnline = false;
bool cameraRemoteReady = false;
bool cameraSdReady = false;
uint32_t lastCameraRxMs = 0;
uint32_t lastPingMs = 0;
uint32_t lastCameraStatusRequestMs = 0;
uint32_t nextCaptureRequestId = 1;

bool missionActive = false;
uint32_t currentMissionNumber = 0;
String currentMissionPath = "";

bool captureRequestPending = false;
uint32_t pendingCaptureRequestId = 0;
int8_t lastCaptureResult = 0;  // 0 waiting/none, 1 OK, -1 failed
uint32_t captureRequestStartedMs = 0;
bool pendingCaptureIsSurvey = false;
uint32_t surveyPhotosRequested = 0;
uint32_t surveyPhotosSaved = 0;
uint32_t surveyPhotosFailed = 0;

// Photo-first manual sweep state must be declared before camera response handling.
bool manualPhotoSweepEnabled = false;
uint32_t manualPhotoLastRequestMs = 0;
float manualPhotoDistanceSinceLastM = 0.0f;
uint32_t manualPhotoSchedulerLastMs = 0;
char manualDriveCommand = '0';

// Dense orthophoto scheduler. The target spacing is deliberately much smaller
// than a normal GPS fix. Along-track GPS progress is used when available, while
// a time deadline guarantees that water motion or GPS jitter cannot create gaps.
constexpr float ORTHO_TARGET_PHOTO_STEP_M = 0.20f;
constexpr uint32_t ORTHO_SOFT_PHOTO_DEADLINE_MS = 850;
constexpr uint32_t ORTHO_HARD_PHOTO_DEADLINE_MS = 1250;
float photoAlongAtLastRequestM = -1000.0f;
uint32_t laneExpectedPhotoCount = 0;
uint32_t laneSavedPhotoCount = 0;
bool lanePhotoCoverageGood = false;

uint8_t consecutiveCaptureFailures = 0;
constexpr uint8_t MAX_CONSECUTIVE_CAPTURE_FAILURES = 5;
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

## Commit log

2026-09-24 Build DeepSeeker research repository
    [M0014_metrics.csv, M0016_mosaic_frame_selection.csv, M0016_quality_metrics.csv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]
2026-09-25 Tighten README hero framing
